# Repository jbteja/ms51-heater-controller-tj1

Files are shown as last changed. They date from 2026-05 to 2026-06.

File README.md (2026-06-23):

# Deterministic Heater Controller

| Property | Value |
|---|---|
| Project ID | tj01 (Previously JBT01) |
| Started | 14th February 2023 |
| Stack | C, Keil uVision, KiCAD 6.0.0, Nuvoton MCUs |
| Keywords | MS51FB9AE, MAX6675, K-Type Thermocouple, T91-30A,<br>110/230V AC to 12V DC SMPS, LCD Display, Timer 2 |
| Status | Completed and delivered to the client. |

## 🚀 Overview

A heater controller project built around the Nuvoton MS51FB9AE. It delivers deterministic operation, safety auto-cutoff, preset timer modes, and temperature measurement using a K‑type thermocouple rated above 750°C.

The custom PCB includes a 16×2 LCD, MAX6675 thermocouple interface, a few switches, and a relay for heater control. The design prioritizes temperature safety and reliable performance in a demanding environment.

## ✍️ Requirement

This device is intended for a medical/sanitary incinerator where the internal chamber exceeds 750°C. The electronics were designed to operate reliably under harsh conditions and maintain stable performance for at least two years.

The initial order was for 100 units, with 6 controller boards to be delivered within 90 days.

Scope included requirements gathering, controller design, PCB and firmware development, mechanical integration support, and field testing to validate reliability.

## 🧩 Project Highlights

- Designed and developed the complete system from scratch, including requirements, hardware, firmware, testing, and delivery.
- Initially targeted STM8/STM32, then switched to the MS51FB9AE because of availability and cost advantages.
- Iteratively improved the design based on feedback and testing, including PCB layout, component selection, and feature updates.
- Used mechanical and PCB co-design to ensure the controller fit the enclosure, remained serviceable, and handled thermal isolation and airflow.

- **Firmware Highlights:**
  - Implemented a state machine to manage operating modes and ensure deterministic behavior.
  - Ported and customized a 16x2 LCD library for the MS51FB9AE with modular pin mapping.
  - Implemented MAX6675 thermocouple support for accurate temperature monitoring and safety control.
  - Added timer modes with automatic cutoff to prevent overheating.
  - Used a superloop architecture to keep the system responsive while managing timer interrupts and state transitions.

## 🔄 Revisions

- **JBT01A** - Initial design and prototype with basic functionality.
- **JBT01B** - Added filtering capacitor and improved PCB layout for better noise immunity.
- **JBT01C** - Added removable LCD headers and improved accessibility and mounting **([Demo Video](https://youtu.be/qEdxYMNRhFU?si=CgpE43CbFfmUwAwB))**.

## ✌️ Controller Board Design

<p align="center">
  <table>
    <tr>
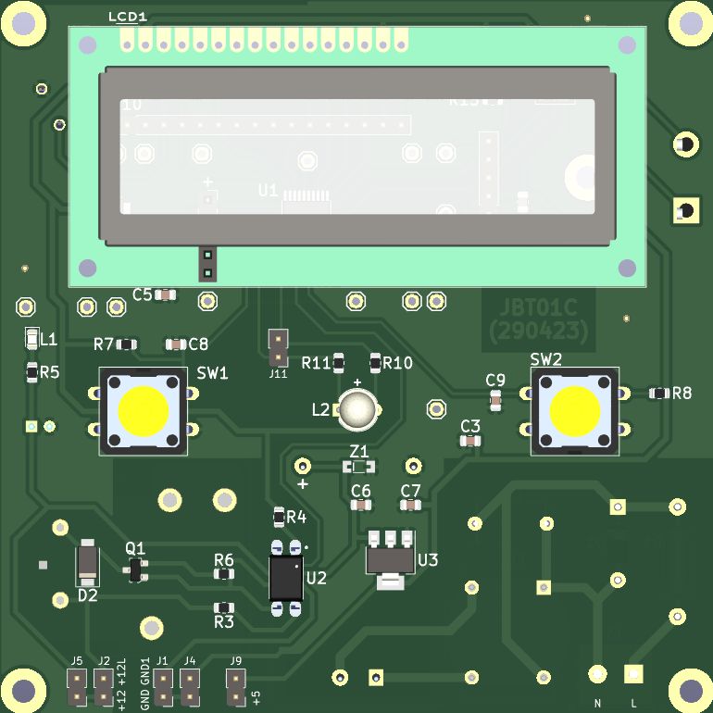
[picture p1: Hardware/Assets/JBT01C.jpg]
      <td align="center"><strong>Top</strong><br></td>
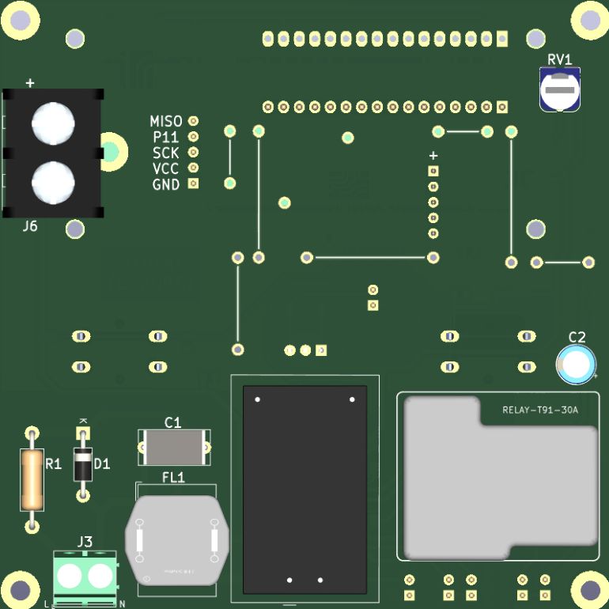
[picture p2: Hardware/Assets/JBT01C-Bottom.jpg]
      <td align="center"><strong>Bottom</strong><br></td>
    </tr>
  </table>
</p>

## 🗂️ Repo Structure

```bash
├───Firmware
│   ├───Keil Project
│   └───Source Files
│
└───Hardware
    ├───3D
    ├───BOM
    ├───Gerbers
    ├───Assets
    └───Source Files
```

## 🔗 VS Code Extensions

```bash
cl.keil-assistant
streetsidesoftware.code-spell-checker
```

## 🏗️ Mechanical & Hardware Co-Design

The device was developed through integrated mechanical and electronic design to ensure reliable operation in an incinerator environment. Mechanical requirements included enclosure space, thermal isolation, airflow, mounting, serviceability, and cable routing. Hardware requirements such as sensor interfaces, relay isolation, display visibility, and maintenance access shaped the enclosure and system layout.

## 🛠️ Proof of Work

<table>
  <tr>
    <td width="33%" align="center">
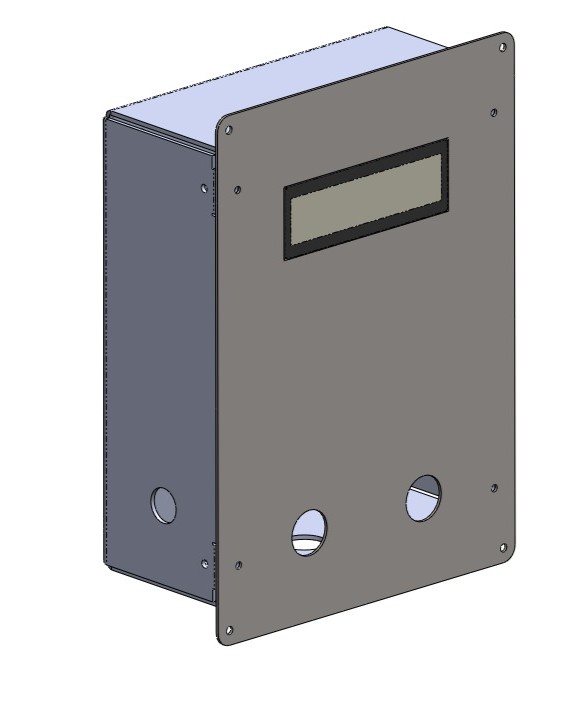
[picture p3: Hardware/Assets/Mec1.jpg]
Enclosure design
      
      <p>Enclosure design</p>
    </td>
    <td width="33%" align="center">
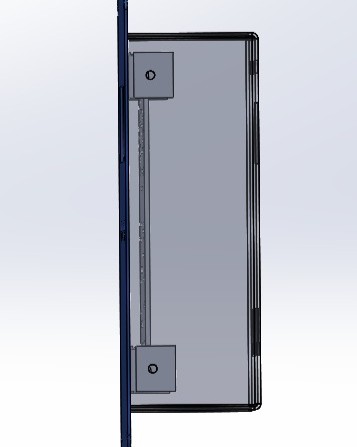
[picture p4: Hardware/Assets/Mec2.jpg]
Enclosure design, Side view
      
      <p>Enclosure design, Side view</p>
    </td>
    <td width="33%" align="center">
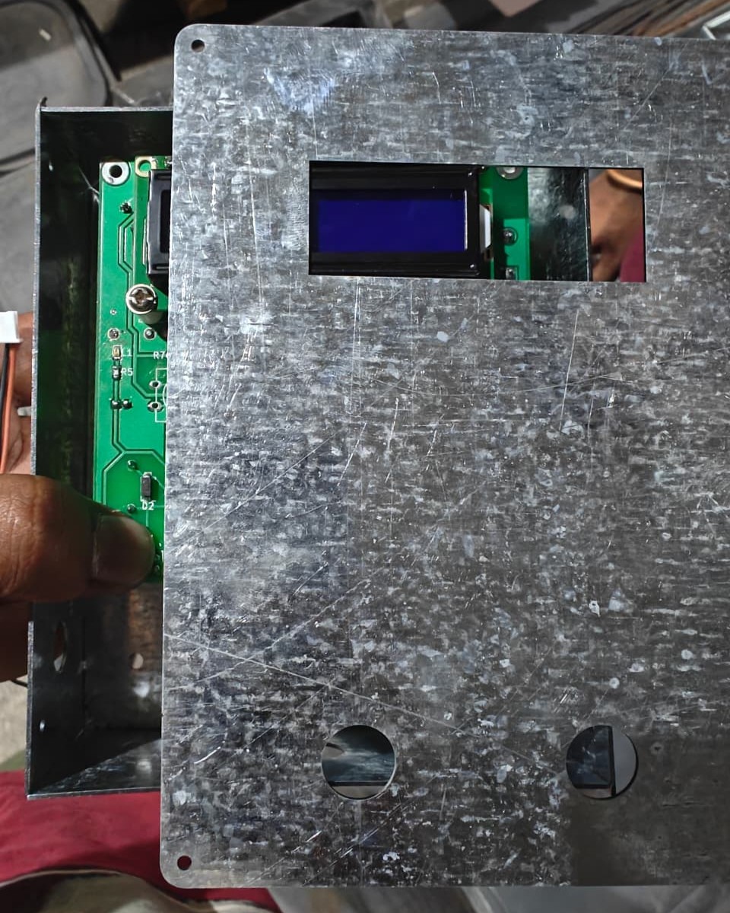
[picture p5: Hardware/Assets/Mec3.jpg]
Enclosure prototype, Front view
      
      <p>Enclosure prototype, Front view</p>
    </td>
  </tr>
  <tr>
    <td width="33%" align="center">
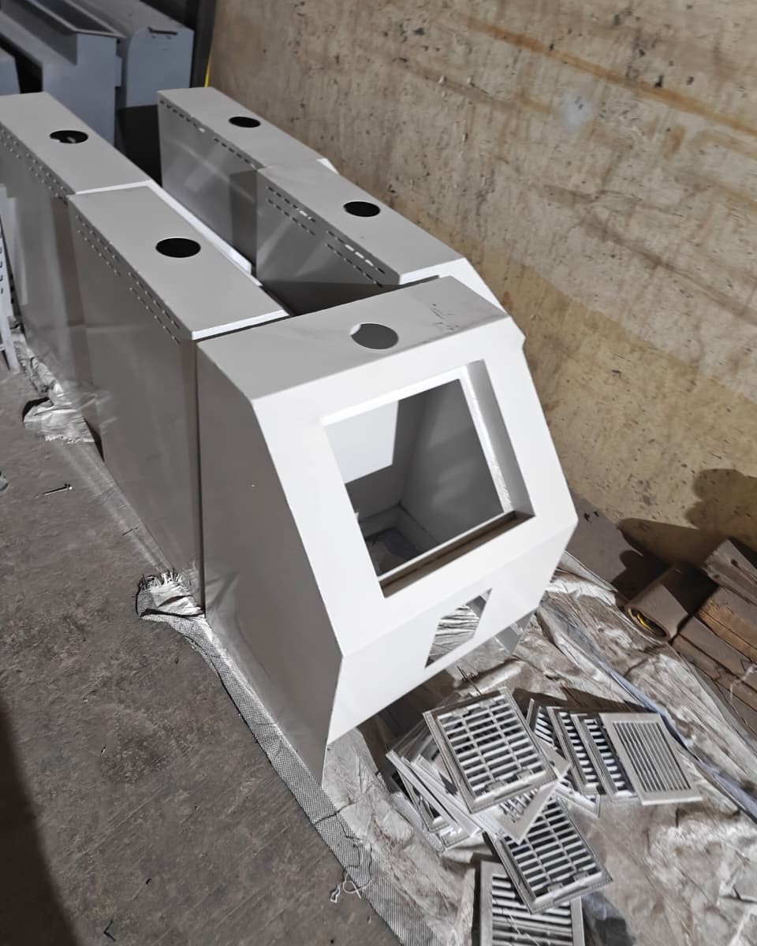
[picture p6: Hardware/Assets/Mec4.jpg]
      
      <p>Mechanical parts before assembly</p>
    </td>
    <td width="33%" align="center">
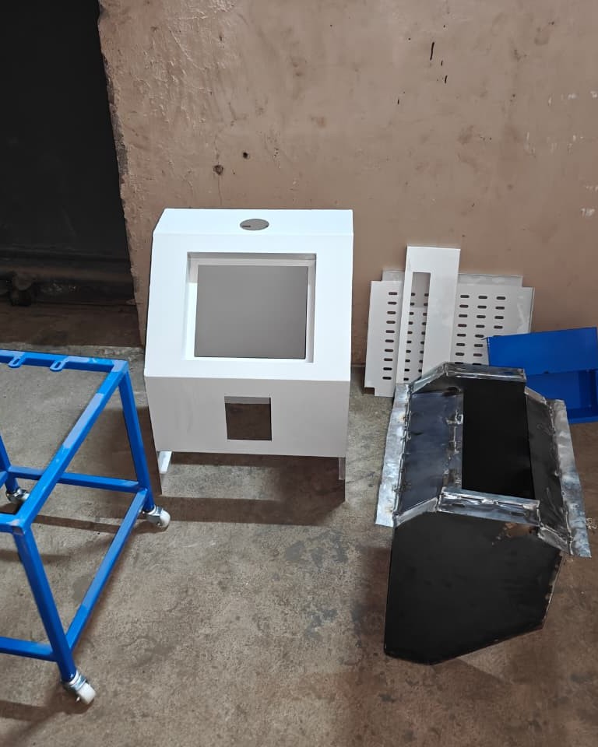
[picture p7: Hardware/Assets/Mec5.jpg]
      
      <p>Mechanical parts before assembly</p>
    </td>
    <td width="33%" align="center">
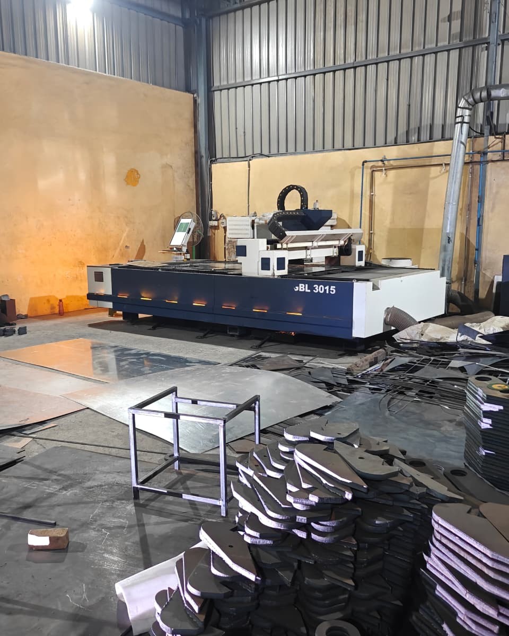
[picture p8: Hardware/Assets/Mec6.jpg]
Laser cut machine setup
      
      <p>Laser cut machine setup</p>
    </td>
  </tr>
  <tr>
    <td width="33%" align="center">
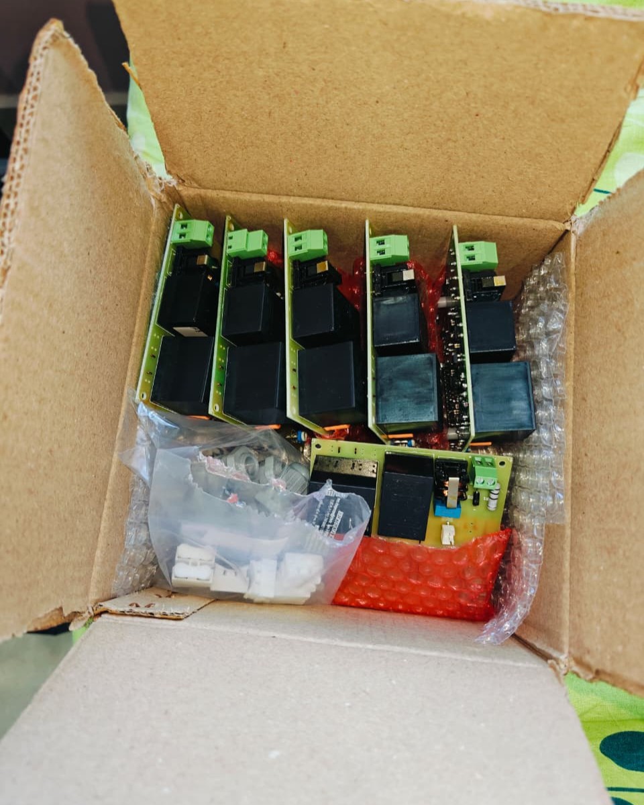
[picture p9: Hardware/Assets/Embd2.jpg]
Tested controllers before delivery
      
      <p>Tested controllers before delivery</p>
    </td>
    <td width="33%" align="center">
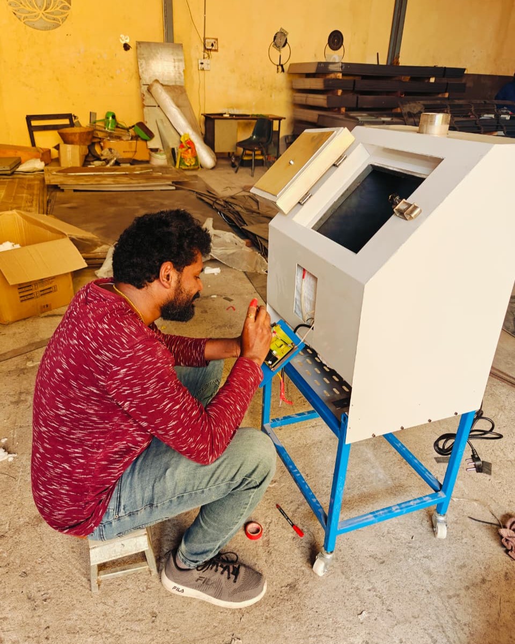
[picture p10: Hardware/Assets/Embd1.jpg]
Inspecting, fixing, and verifying electrical connections
      
      <p>Inspecting, fixing, and verifying electrical connections</p>
    </td>
    <td width="33%" align="center">
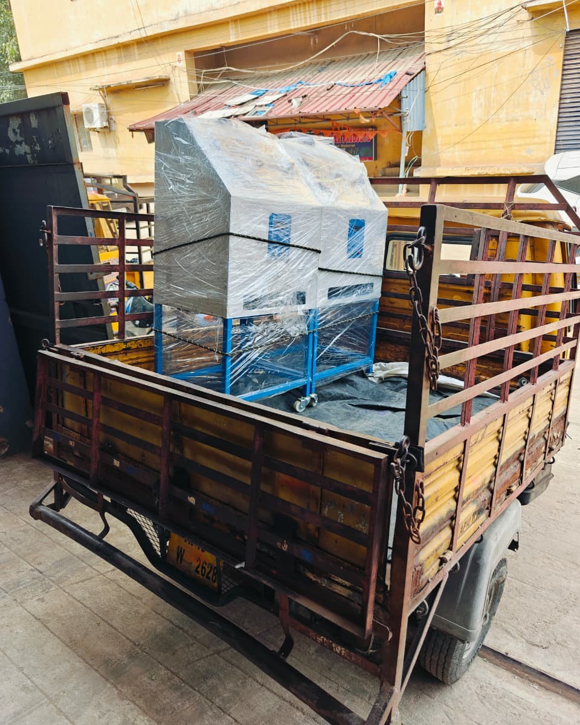
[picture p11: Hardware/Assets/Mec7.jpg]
Tested and ready to be dispatched
      
      <p>Tested and ready to be dispatched</p>
    </td>
  </tr>
  <tr>
    <td width="33%" align="center">
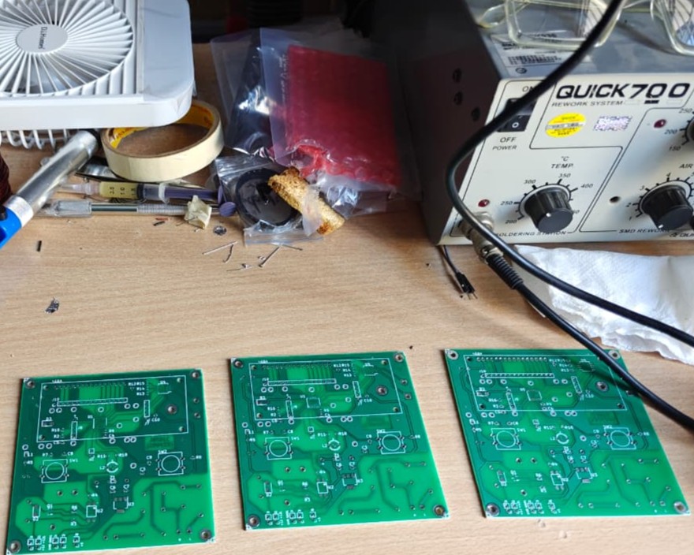
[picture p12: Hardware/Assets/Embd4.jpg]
PCBs before assembly
      
      <p>PCBs before assembly</p>
    </td>
    <td width="33%" align="center">
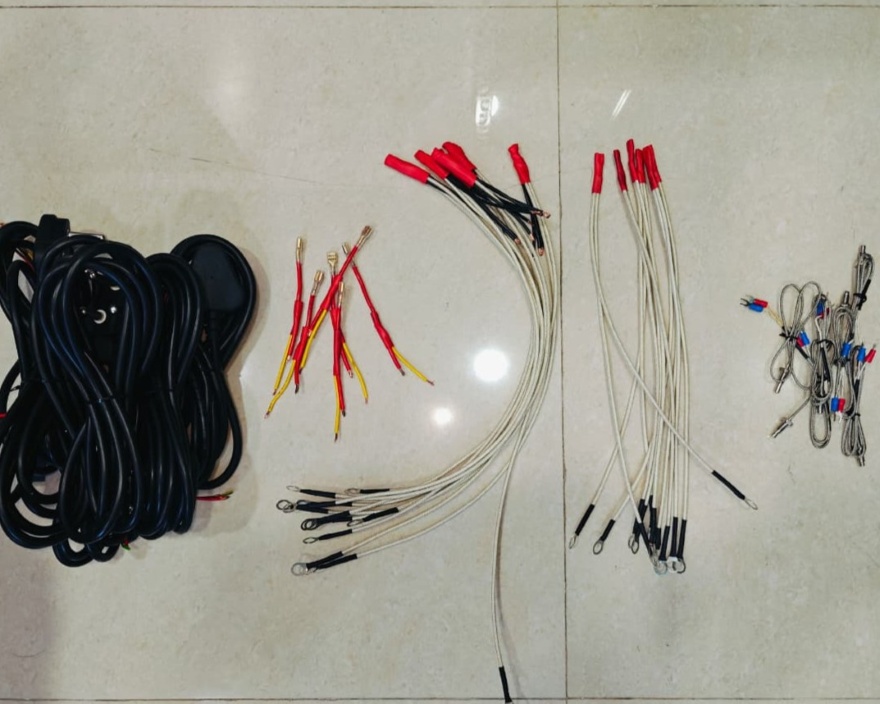
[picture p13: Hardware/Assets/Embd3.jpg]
Cables and connectors
      
      <p>Cables and connectors</p>
    </td>
    <td width="33%" align="center">
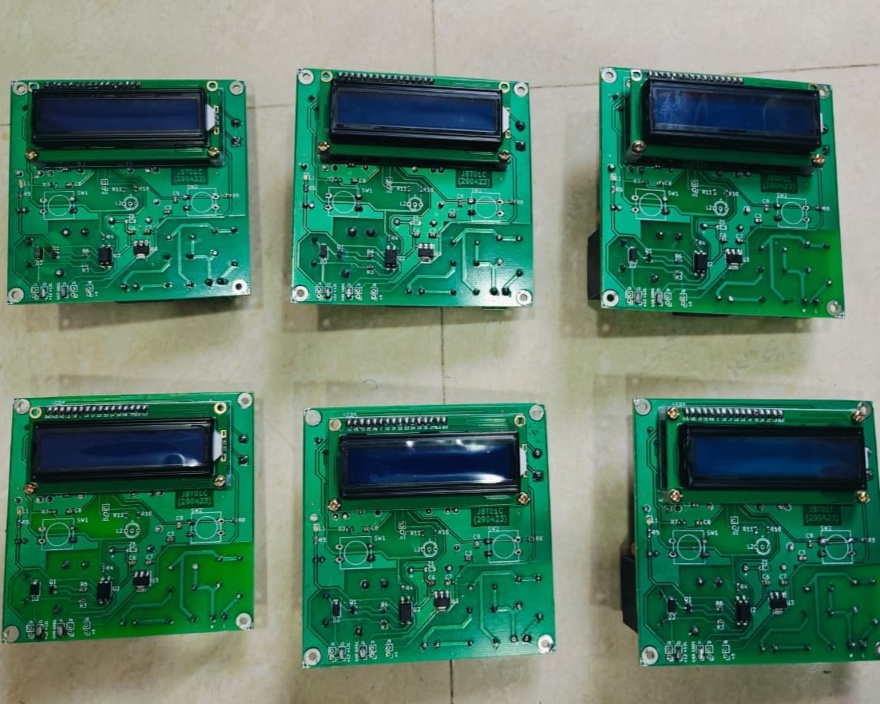
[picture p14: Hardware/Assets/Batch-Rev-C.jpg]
PCBs after assembly, Front view
      
      <p>PCBs after assembly, Front view</p>
    </td>
  </tr>
</table>

## 🏷️ Video Demos

<table>
  <tr>
    <td width="33%" align="center">
      <video src="https://github.com/user-attachments/assets/38caba92-163d-486c-91cd-d47db43cc024" width="100%" controls controlsList="nodownload" muted playsinline></video>
      <p>Controllers</p>
    </td>
    <td width="33%" align="center">
      <video src="https://github.com/user-attachments/assets/006b11b3-cdbf-497a-a6c1-e160840782f8" width="100%" controls controlsList="nodownload" muted playsinline></video>
      <p>Test cycle</p>
    </td>
    <td width="33%" align="center">
      <video src="https://github.com/user-attachments/assets/03c04a3a-10fb-4163-b0c6-8f93c4f1aaef" width="100%" controls controlsList="nodownload" muted playsinline></video>
      <p>Test cycle</p>
    </td>
  </tr>
</table>

## 📌 Conclusion & Current Status

The project requirements were successfully met and delivered within the specified timeline, with 20 controller units delivered and deployed in the field. Although an initial requirement of 100 units was anticipated, the full order was not fulfilled by the client. However, the delivered controllers have been operating reliably, meeting the requirement of stable performance for at least two years. The project has been a valuable learning experience in embedded system design, hardware-software co-design, and project management.

**Of the controller boards delivered, all except one remain functional and in good operating condition after nearly two years of field deployment**. The single failure was due to a surge in the power supply, which bricked the SMPS unit.

Following the first year of operation, scheduled maintenance was provided from our side. At the time of this writing, all deployed machines continue to operate successfully, demonstrating reliability under real-world operating conditions.

## ✏️ Miscellaneous & Notes

### 1. Project Backstory

This requirement came from within my professional network, and since I knew them personally, I had to pitch in on an urgent basis.

The pain point? The previous PCBs used in earlier machines kept failing every 6 to 9 months, causing repeated downtime. The client had already spent a significant amount on replacements and repairs.

The original design was not only costly but also lacked basic engineering foresight. It used a separate, bulky power supply, had no proper connectors or terminals for heater integration, and offered no thermal isolation or reliable mounting.

The previous client's control board cost 2.5 times more than the one I ultimately delivered and assembled.

In the end, a reliable, cost‑effective controller replaced the overpriced design, and machine wire routing placeholders were included in the mechanical design.

### 2. LCD Driver/Library Development

Reused, tested and adapted an existing 16x2 LCD library for the MS51FB9AE, which is compatible with HD44780 and ST7066 controllers. The library supports modular pin mapping and 4-bit mode, allowing for flexible hardware configurations. It provides functions for initializing the LCD, sending commands and data, and displaying characters and strings on the screen.

### 3. Repository Naming Convention

Before I started naming projects in a sequence, I had worked on many projects. When I went back to reuse content or refer to specific details, I usually struggled to find them or had already lost track of them.

Over time, I decided to standardize the naming with “TJ” and continue using it consistently, grouping and organizing both old and new projects into a structured sequence.

Not all projects can be shared publicly because of client restrictions or ownership agreements. As a result, the sequence may have gaps where some projects are not listed or documented. However, I maintain a private record of all projects for my reference and learning.

### 4. Privacy‑First Assets

All images in this repository have been stripped of metadata to protect privacy and sensitive information. This ensures that no unintended data is shared when the images are viewed or downloaded.

Used **exiftool** to remove metadata from images:

```bash
exiftool -all= -P -overwrite_original *.png
exiftool -all= -P -overwrite_original *.jpg
exiftool -all= -P -overwrite_original *.mp4
```

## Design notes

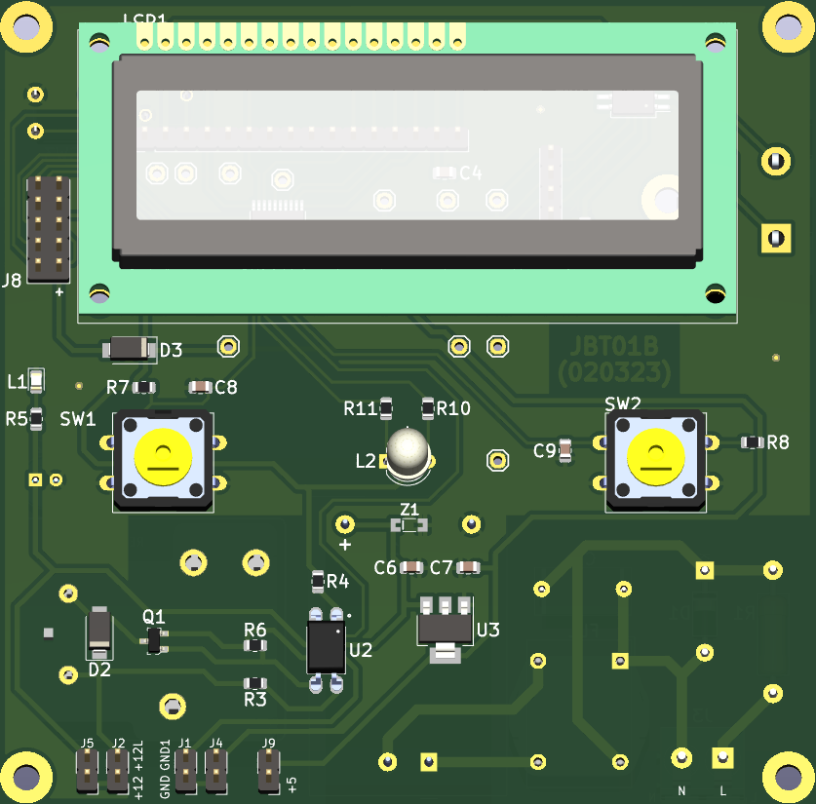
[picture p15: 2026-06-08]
Hardware/Assets/JBT01B.png

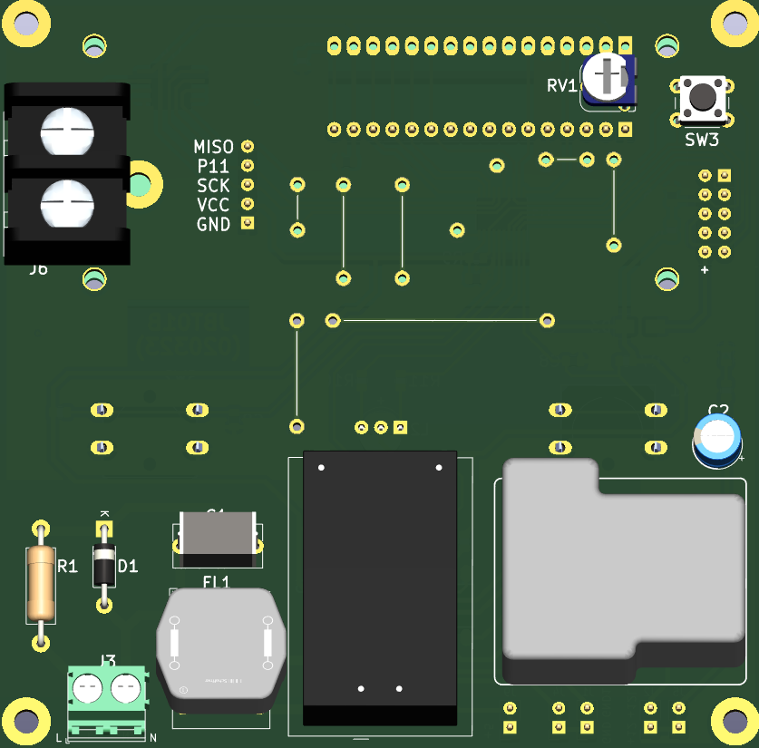
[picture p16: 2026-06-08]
Hardware/Assets/JBT01B-Bottom.png

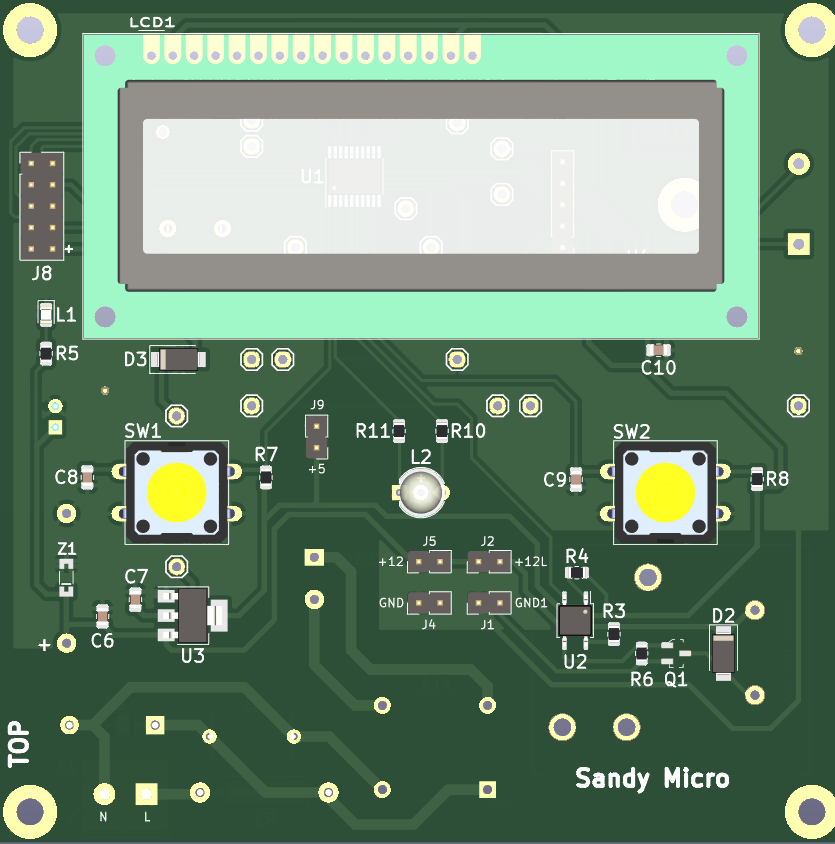
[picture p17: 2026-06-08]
Hardware/Assets/JBT01A.png

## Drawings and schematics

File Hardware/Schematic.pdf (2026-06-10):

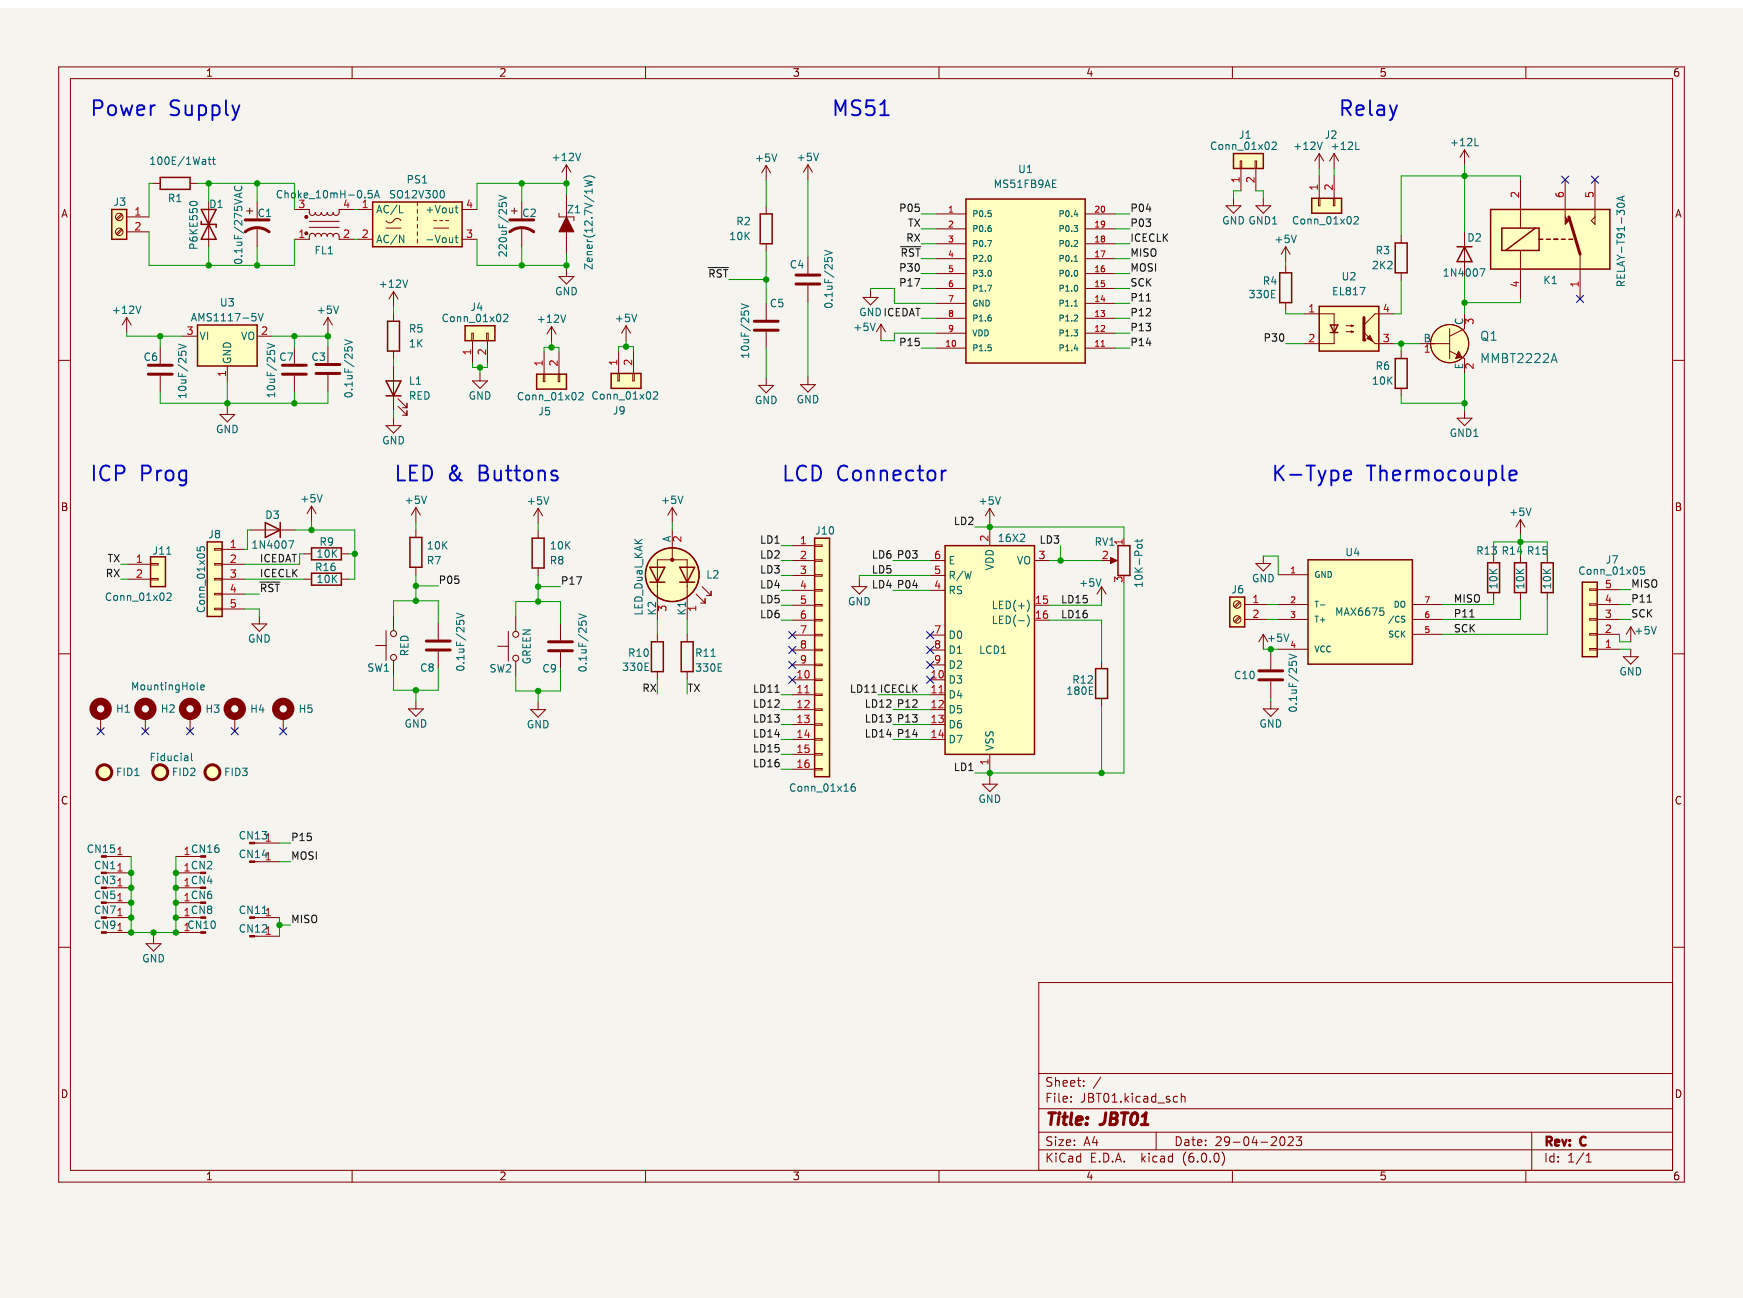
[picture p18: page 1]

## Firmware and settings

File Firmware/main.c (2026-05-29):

#include "global.h"

const char allStringsDpy[][17] = {
  //"1234567890123456\0"
    "  Sanitary Pad  \0",
    "   Incinerator  \0",
    "    Hygienic    \0",
    "    Disposal    \0",
    "Pres Red to Stop\0",
    " Green to Start \0" 
};

float vTemp = 0.0;
uint8_t tempStr[9] = {'\0'};
uint8_t heaterState = 0, lastState = 0;
uint8_t toggle = 1, lastToggle = 0, dpy = 0;
int8_t sec = 0, min = 0, hrs = 0, lastSec = -1;
uint32_t millies = 0, pmillies = 0, ms = 0;
uint8_t arySize = sizeof(allStringsDpy) / sizeof(allStringsDpy[0]);

/* Liquid crystal display state functions */
void display_on_state(void){
    LiquidCrystal_clear();
    LiquidCrystal_setCursor(0, 0);
    LiquidCrystal_putStr("Switching On");
    delay_ms(250);
    LiquidCrystal_clear();
}

void display_off_state(void){
    LiquidCrystal_clear();
    LiquidCrystal_setCursor(0, 0);
    LiquidCrystal_putStr("Switching Off");
    delay_ms(250);
    LiquidCrystal_clear();
}

void display_exe_state(void) {
    float tr = 0.00;
    uint8_t ittr;

    if (sec != lastSec) {
        // Max6675 in Degrees
        for (ittr = 0; ittr < TEMP_SENSOR_SAMPLES; ittr++) {
            tr += Max6675_readCelsius();
            delay_ms(10);
            if (tr == 0.00) {
                break;
            }
        }
        tr = tr / TEMP_SENSOR_SAMPLES;

        LiquidCrystal_setCursor(0, 0);
        LiquidCrystal_putStr("Time ->");
        display_char(8, 0, hrs);
        display_char(11, 0, min);
        display_char(14, 0, sec);
        
        LiquidCrystal_setCursor(0, 1);
        LiquidCrystal_putStr("Temp ->");
        LiquidCrystal_setCursor(8, 1);
        
        if (tr == 0.00) {
            LiquidCrystal_putStr(" Error! ");
        } else {
            float_to_str(tune_rcvd_val(tr), 2, tempStr);
            LiquidCrystal_putStr("      ");
            LiquidCrystal_setCursor(8, 1);
            LiquidCrystal_putStr(tempStr);
            LiquidCrystal_setCursor(14, 1);
            LiquidCrystal_putChar(0xDF);
            LiquidCrystal_putChar('C');
        }

        lastSec = sec;
    }

    // For clock effect
    if (toggle != lastToggle) {
        if(toggle) {
            LiquidCrystal_setCursor(10, 0);
            LiquidCrystal_putChar(':');
            LiquidCrystal_setCursor(13, 0);
            LiquidCrystal_putChar(':');
        } else {
            LiquidCrystal_setCursor(10, 0);
            LiquidCrystal_putChar(' ');
            LiquidCrystal_setCursor(13, 0);
            LiquidCrystal_putChar(' ');
        }
        lastToggle = toggle;
    }
}

void display_exe_state_valid_temp(void) {
    float tr = 0.00;
    uint8_t ittr, vSamples = 0;

    if (sec != lastSec) {
        // Read temp only if DISPLAY_TEMP is enabled
        if (DISPLAY_TEMP == 1) {
            // Max6675 in Degrees
            for (ittr = 0; ittr < TEMP_SENSOR_SAMPLES; ittr++) {
                float tc = Max6675_readCelsius();
                delay_ms(10);

                // Only accumulate valid readings
                if (tc != 0.00) {
                    tr += tc;
                    tc = 0.00;
                    vSamples++;
                
                } else { 
                    break;
                }
            }

            // Average only if we have valid samples
            if (vSamples > 0) {
                tr /= vSamples;
                vSamples = 0;
            
                // Only update vTemp if the new temp is higher
                if (tr > vTemp) {
                    vTemp = tr;
                    tr = 0.00;
                }
            }
        }

        // Display the time
        LiquidCrystal_setCursor(0, 0);
        LiquidCrystal_putStr("Time ->");
        display_char(8, 0, hrs);
        display_char(11, 0, min);
        display_char(14, 0, sec);

        // Display the temperature only if DISPLAY_TEMP is 1 and the temperature is valid
        if (DISPLAY_TEMP == 1 && vTemp > 0.01) {
            LiquidCrystal_setCursor(0, 1);
            LiquidCrystal_putStr("Temp ->");
            LiquidCrystal_setCursor(8, 1);

            float_to_str(tune_rcvd_val(vTemp), 2, tempStr);
            LiquidCrystal_putStr(tempStr);
            LiquidCrystal_setCursor(14, 1);
            LiquidCrystal_putChar(0xDF);  // Degree symbol
            LiquidCrystal_putChar('C');
        }

        lastSec = sec;
    }

    // Toggle for clock blinking effect
    if (toggle != lastToggle) {
        LiquidCrystal_setCursor(10, 0);
        LiquidCrystal_putChar(toggle ? ':' : ' ');
        LiquidCrystal_setCursor(13, 0);
        LiquidCrystal_putChar(toggle ? ':' : ' ');
        lastToggle = toggle;
    }
}

void display_normal_state(uint8_t strIdx) {
        LiquidCrystal_clear();
        LiquidCrystal_setCursor(0, 0);
        LiquidCrystal_putStr(allStringsDpy[strIdx]);
        LiquidCrystal_setCursor(0, 1);
        LiquidCrystal_putStr(allStringsDpy[strIdx+1]);
}

/* Heater and Timer1 ON and OFF functions */
void heater_on(void) {
    RLY_PIN = LOW;
    LED_GRN = LOW;
    LED_RED = HIGH;
    heaterState = HIGH;

    // Set clock for heater operation
    ms = 0;
    hrs = ONHRS;
    min = ONMIN;
    sec = ONSEC;

    // Safety clock
    if (IS_SENSOR == 1) {
        float tc = Max6675_readCelsius();

        if (tc > 0.01 && tc > SAFE_TEMP) {
            min = SAFE_ONMIN;
        }
    }

    toggle = 0;
    set_timer1_tl_th(DIV12_1ms);
    ENABLE_TIMER1_INTERRUPT;
    SET_INT_Timer1_LEVEL3;
    set_TCON_TR1; // Timer 1 Run
}

void heater_off(void) {
    RLY_PIN = HIGH;
    LED_GRN = HIGH;
    LED_RED = LOW;

    // Clock
    lastToggle = 1;
    clr_TCON_TR1; // Timer 1 Stop
    DISABLE_TIMER1_INTERRUPT;
}

void heater_auto_cutoff(void) {
    if ((sec == 0) && (min == 0) && (hrs == 0)) {
        heaterState = LOW;
    } else {
        display_exe_state_valid_temp();
    }
}

void count_down_clock(void) {
    ms++;
    if(ms == 499) {
      toggle = ~toggle;
    } else if (ms > 999) {
        ms = 0;
        sec--;
        if (sec == -1) {
            sec = 59;
            min--;
            if (min == -1) {
                min = 59;
                if(hrs != 0) {
                    hrs --;
                }
            }
        }
    }
}

/* Timer 0, 1 & External Int1 ISR functions */
void Timer0_ISR (void) interrupt 1 {
    _push_(SFRS);
    millies++;
    set_timer0_tl_th(DIV12_1ms);
    clr_TCON_TF0;
    _pop_(SFRS);
}

void INT1_ISR (void) interrupt 2 {
	_push_(SFRS);
    heaterState = LOW;
	clr_TCON_IE1;
	_pop_(SFRS);
}

void Timer1_ISR (void) interrupt 3 {
    _push_(SFRS);
    count_down_clock();
    set_timer1_tl_th(DIV12_1ms);
    clr_TCON_TF1;
    _pop_(SFRS);
}

/* Initial SetUp */
void setup(void) {
	GPIO_init();
	MAX6675_GPIO_init();
    Max6675_SPI_init();

    // Timer 0
    start_timer0_mode1(DIV12_1ms);

	// Ext Int 1
	set_P17;
	INT1_LOW_LEVEL_TRIG;
    set_IE_EX1;

    // Timer 1
    ENABLE_TIMER1_MODE1;
    TIMER1_FSYS_DIV12;

	// Heater
    heater_off();

    // LCD
    LiquidCrystal_init(16, 2, 0);
    LiquidCrystal_clear();
    LiquidCrystal_setCursor(4, 0);
    LiquidCrystal_putStr("WELCOME");
    LiquidCrystal_setCursor(2, 1);
    
    LiquidCrystal_putStr("Sandi Community");
    delay_ms(300);
    display_normal_state(dpy);
    
    ENABLE_GLOBAL_INTERRUPT;
}

/* Main */
void main(void) {	
  setup();

  while(1) {
    if ((heaterState == LOW) && (lastState == HIGH)) {
        heater_off();
        display_off_state();
        lastState = LOW;

    } else if ((heaterState == LOW) && (SW_SART == LOW)) {
        display_on_state();
        heater_on();
        lastState = HIGH;

    } else if ((heaterState == HIGH) && (lastState == HIGH)) {
        heater_auto_cutoff();

    } else {
        if ((millies - pmillies) >= LCD_NRL_DPY_INT) {
            (dpy < (arySize - 2)) ? (dpy += 2) : (dpy = 0);
            display_normal_state(dpy);
            pmillies = millies;
        }
    }
  }
}

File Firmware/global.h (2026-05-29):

#ifndef MS51_GLOBALS_H
#define MS51_GLOBALS_H

#include "MS51_16K.H"
#include "lcd.h"
#include "spi.h"
#include "max6675.h"

// Temperate sensor
#define IS_SENSOR 1
#define DISPLAY_TEMP 1
#define TEMP_SENSOR_SAMPLES 3

// CountDown Timer
#define ONHRS 0
#define ONMIN 15
#define ONSEC 0

// Safe CountDown Timer
#define SAFE_ONMIN 10
#define SAFE_TEMP 320.00

// Retry interval
#define LCD_NRL_DPY_INT 6*1000 // Sec

// Timer 1
#define DIV12_1ms TIMER_DIV12_VALUE_1ms_FOSC_16000000+26

// Soft Delay 
#define osc_freq_in_MHz 16
#define osc_scalar (24 / osc_freq_in_MHz)

// LCD
#define RS_PIN  P04
#define EN_PIN  P03
#define DB4_PIN P02
#define DB5_PIN P12
#define DB6_PIN P13
#define DB7_PIN P14

// LED
#define LED_RED P06
#define LED_GRN P07

// Buttons
#define SW_SART P05
#define SW_STOP P17
#define SW_CNFG P16

// Relay
#define RLY_PIN P30

// Thermocouple K-Type
#define MAX6675_SO P01
#define MAX6675_CK P10
#define MAX6675_CS P11

// PinMode
#define GPIO_init() do{\
    P04_PUSHPULL_MODE; \
    P03_PUSHPULL_MODE; \
    P02_PUSHPULL_MODE; \
    P12_PUSHPULL_MODE; \
    P13_PUSHPULL_MODE; \
    P14_PUSHPULL_MODE; \
    P06_PUSHPULL_MODE; \
    P07_PUSHPULL_MODE; \
    P05_INPUT_MODE; \
    P16_INPUT_MODE; \
    P17_QUASI_MODE; \
    P30_PUSHPULL_MODE; \
    } while(0);

#define MAX6675_GPIO_init() do{\
    P01_QUASI_MODE; \
    P10_QUASI_MODE; \
    P11_QUASI_MODE; \
    } while(0);

void delay_us(uint32_t value);
void delay_ms(uint32_t value);

void set_timer0_tl_th(uint16_t value);
void start_timer0_mode1(uint16_t value);
void stop_timer0_mode1(void);
void set_timer1_tl_th(uint16_t value);

uint8_t count_digits(uint32_t digt);
float tune_rcvd_val(float f);
void float_to_str(float f, uint8_t decimalPoint, uint8_t *outStr);

void display_char(uint8_t x_pos, uint8_t y_pos, uint8_t value);
void display_uint(uint8_t x_pos, uint8_t y_pos, uint16_t value);

#endif

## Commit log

2026-05-29 Refactor temperature handling and display logic
2026-05-30 Update KiCad files of Rev C and enhance schematic title block
    [JBT01.kicad_sch]
2026-06-08 Added RevC BOM
2026-06-10 Added RevC schematic
2026-06-10 Fix links for Prototype-Test1 and Prototype-Test2 videos
    Updated links for Test cycle videos in README.
